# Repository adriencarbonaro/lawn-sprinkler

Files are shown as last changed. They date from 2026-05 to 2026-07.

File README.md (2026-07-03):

# Lawn sprinkler controller

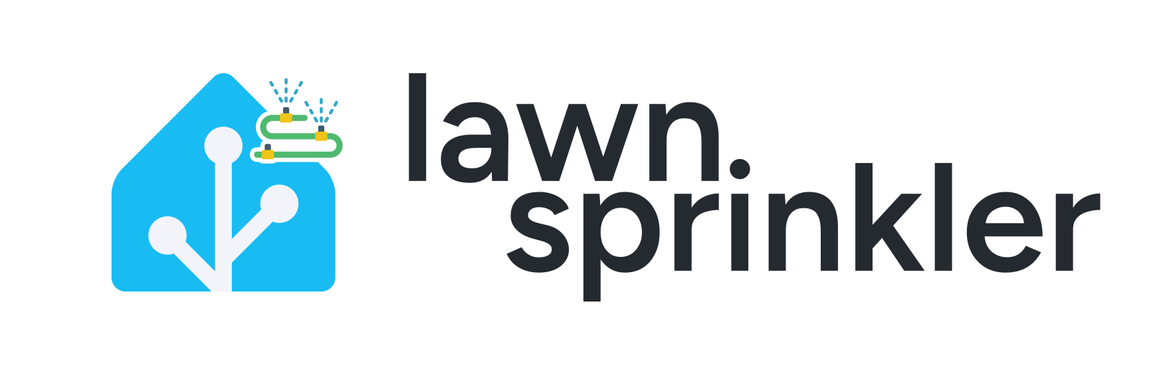
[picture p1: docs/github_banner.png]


## 1. Overview

ESP32 based firmware (ESP-IDF / FreeRTOS) for a 6-zone lawn-sprinkler controller.
Drives 6 active-high triac outputs with mutual exclusion (only one zone
ever on at a time), and use 6 ON/OFF buttons for Home Assistant.

State is exchanged over MQTT, and on (re)connect
the device publishes a single Home Assistant device-discovery payload — all
entities (mode select, duration select, six per-zone switches, version sensor)
appear grouped under one device, no manual HA configuration required.

## 2. Features

### 2.1. **MANUAL mode** :

1. On the control box:

    a) Pressing one of the 6 push buttons starts watering the zone and stops watering the other zones.

    b) Pressing it a second time stops watering the zone.

    c) If AUTO mode is active, it switches to manual mode.

    d) The system automatically returns to AUTO mode after 30 minutes without a zone being manually activated.

2. On the HA app:

    Set a duration, then select a zone to water.

### 2.2. Status LED

- **STATUS LED** : gives indication on the status of the lawn sprinkler controller
  - OFF: The device is turned off
  - Solid ON: The device is booting up
  - low flashing (100ms ON, 3000ms period): The device is connected to Wi-Fi/MQTT
  - Fast flashing (500ms ON, 1000ms period): The device was unable to connect to Wi-Fi/MQTT
- **Zone LED** : Each zone has a LED indicating whether the zone is active or not-
  - ON : the zone is currently active
  - OFF: the zone is inactive

## 3. Hardware

### 🙌 Sponsor

Huge thanks to **PCBWay** for sponsoring the PCB manufacturing for this project.
Their support, help and advices helped make this project physically real.

If you're looking for high-quality PCB fabrication or assembly services, check them out:

👉 https://www.pcbway.com

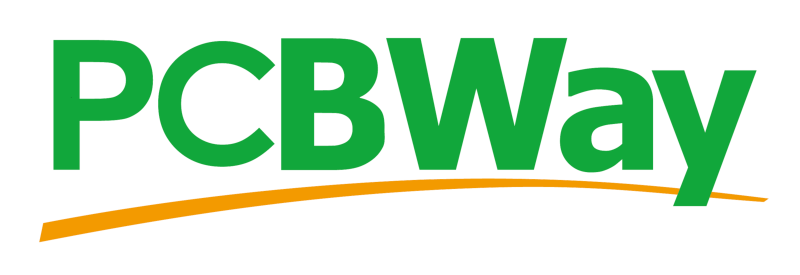
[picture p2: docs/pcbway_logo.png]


Designed around a Waveshare esp32-C6 dev kit N8.
Drives 6 triac BT136-600 in Dpak package
Uses former Rainbird ESP-RXZe controller housing and its 24Vac/0.65A transformer

## 4. Software

Developped with esp idf on freeRTOS architecture

### 4.1. Build & flash

```bash
. $IDF_PATH/export.sh
make build
make flash PORT=/dev/<port> # example: /dev/ttyACM0
make monitor
```

`make_version.py` derives `VERSION` and `BUILD_ID_SHORT` from `git describe`,
so make sure at least one tag exists (e.g. `git tag v0.1.0`).

### 4.2. Project layout

```
main/
  zone/        6 active-high outputs (MOC3041 triac drivers), mutual exclusion
  button/      6 push buttons via iot_button, one click -> controller event
  controller/  AUTO/MANUAL state machine, run/idle timers
  wifi/        Wi-Fi STA + SNTP/timezone
  mqtt/        MQTT client, topic dispatcher, Home Assistant discovery
```

### 4.3. Configuration

Set via `idf.py menuconfig` -> *Lawn Sprinkler Controller Settings*:

### 4.4. MQTT API

With `MQTT_TOPIC_PREFIX = "lawn-sprinkler/"`:

#### Subscribed (HA -> device)

| Topic | Payload | Effect |
| --- | --- | --- |
| `lawn-sprinkler/mode/set` | `AUTO` \| `MANUAL`  | Switch mode |
| `lawn-sprinkler/duration/set` | minutes (e.g. `10`) | Set MANUAL default duration |
| `lawn-sprinkler/zone/<n>/set` | `ON` \| `OFF` | Toggle zone (uses the current MANUAL duration) |

#### Published (device -> HA), retained

| Topic | Payload |
| --- | --- |
| `lawn-sprinkler/mode/state` | `AUTO` \| `MANUAL` |
| `lawn-sprinkler/duration/state` | minutes (e.g. `10`) |
| `lawn-sprinkler/zone/<n>/state` | `ON` \| `OFF` |
| `lawn-sprinkler/availability` | `online` (LWT: `offline`)  |
| `lawn-sprinkler/version` | `vX.Y.Z - <git-short-sha>` |

### 4.5. Home Assistant discovery

On every (re)connect the device publishes a single retained message using
Home Assistant's device-based discovery:

- `homeassistant/device/<DEVICE_ID>/config`

The payload describes the device once and lists every component nested under
`components`:

- `mode` - select (`AUTO` / `MANUAL`)
- `duration` - number (`0..60` minutes, `step=1`) — default applied to a manual button press
- `zone_0` ... `zone_5` - one switch per zone
- `version` - diagnostic sensor (firmware version + short build id)

Shared `device`, `origin` and `availability` blocks live at the top of the
payload, so all entities are grouped under one device in HA and follow the
same online/offline state via the `availability` topic.

### 4.6 Home Assistant card

Notes:

- This example uses `custom:button-card` which must be downloaded first. If you want a simpler option using only the UI, you can display the switches from MQTT discovery.

First, we need to create the template in Dashboard UI. This prevent a lot of duplication, as we will need it for each zone button. Go to your dashboard, then click *Edit* > *Raw Configuration Editor*. Paste the following snippet at the top. Modify the colors and style according to your needs.

```yml
button_card_templates:
  lawn_sprinkler_button_base:
    icon: mdi:sprinkler-variant
    show_name: true
    show_state: false
    layout: icon_name
    styles:
      card:
        - padding: 8px
        - height: 48px
        - border-radius: 12px
        - '--zone-color': var(--blue-color)
      name:
        - padding-left: 0px
        - color: var(--zone-color)
        - justify-self: start
        - font-size: 10pt
        - font-weight: 500
      icon:
        - width: 26px
        - height: 26px
        - color: var(--zone-color)
    state:
      - value: 'on'
        styles:
          card:
            - background-color: var(--zone-color)
          icon:
            - color: white
    tap_action:
      action: call-service
      service: switch.toggle
```

Then, create the cards.

```yml
type: vertical-stack
cards:
  - type: horizontal-stack
    cards:
      - type: tile
        entity: select.lawn_sprinkler_mode
        features_position: bottom
        vertical: false
        color: deep-orange
        name: Mode
        hide_state: false
        state_content:
          - state
          - last_changed
        grid_options:
          columns: full
        icon_tap_action:
          action: none
        tap_action:
          action: more-info
      - type: tile
        entity: select.lawn_sprinkler_duration
        features_position: bottom
        vertical: false
        name: Duration
        hide_state: false
        state_content:
          - state
        icon_tap_action:
          action: none
        tap_action:
          action: more-info
  - type: horizontal-stack
    cards:
      - type: custom:button-card
        template: lawn_sprinkler_button_base
        entity: switch.lawn_sprinkler_zone_0
        name: ZONE_1
        styles:
          card:
            - "--zone-color": var(--blue-color)
        tap_action:
          action: call-service
          service: switch.toggle
          target:
            entity_id: switch.lawn_sprinkler_zone_0
      - type: custom:button-card
        template: lawn_sprinkler_button_base
        entity: switch.lawn_sprinkler_zone_1
        name: ZONE_2
        styles:
          card:
            - "--zone-color": var(--green-color)
        tap_action:
          action: call-service
          service: switch.toggle
          target:
            entity_id: switch.lawn_sprinkler_zone_1
      - type: custom:button-card
        template: lawn_sprinkler_button_base
        entity: switch.lawn_sprinkler_zone_2
        name: ZONE_3
        styles:
          card:
            - "--zone-color": var(--purple-color)
        tap_action:
          action: call-service
          service: switch.toggle
          target:
            entity_id: switch.lawn_sprinkler_zone_2
  - type: horizontal-stack
    cards:
      - type: custom:button-card
        template: lawn_sprinkler_button_base
        entity: switch.lawn_sprinkler_zone_3
        name: ZONE_4
        styles:
          card:
            - "--zone-color": var(--red-color)
        tap_action:
          action: call-service
          service: switch.toggle
          target:
            entity_id: switch.lawn_sprinkler_zone_3
      - type: custom:button-card
        template: lawn_sprinkler_button_base
        entity: switch.lawn_sprinkler_zone_4
        name: ZONE_5
        styles:
          card:
            - "--zone-color": var(--cyan-color)
        tap_action:
          action: call-service
          service: switch.toggle
          target:
            entity_id: switch.lawn_sprinkler_zone_4
      - type: custom:button-card
        template: lawn_sprinkler_button_base
        entity: switch.lawn_sprinkler_zone_5
        name: ZONE_6
        styles:
          card:
            - "--zone-color": var(--yellow-color)
        tap_action:
          action: call-service
          service: switch.toggle
          target:
            entity_id: switch.lawn_sprinkler_zone_5
```

Notes:

- The entity names must match between the MQTT discovery and the yml snippet.

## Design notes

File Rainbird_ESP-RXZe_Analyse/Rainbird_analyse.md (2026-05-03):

# Lawn Sprinkler Controller
# RAINBIRD ESP-RXZe

## 1. Description

### 1.1 External description

**EVs wiring**
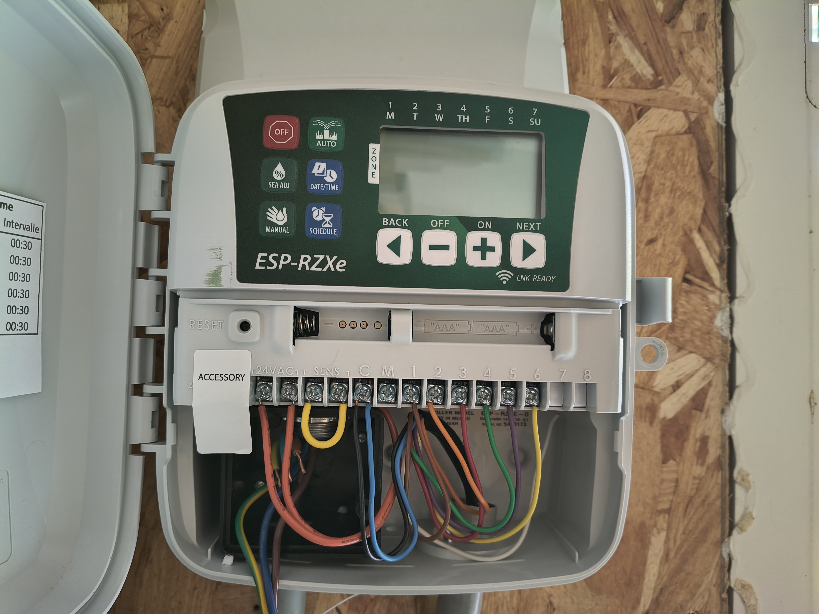
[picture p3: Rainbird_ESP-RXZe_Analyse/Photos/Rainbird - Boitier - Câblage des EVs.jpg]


**Electronic board removed**
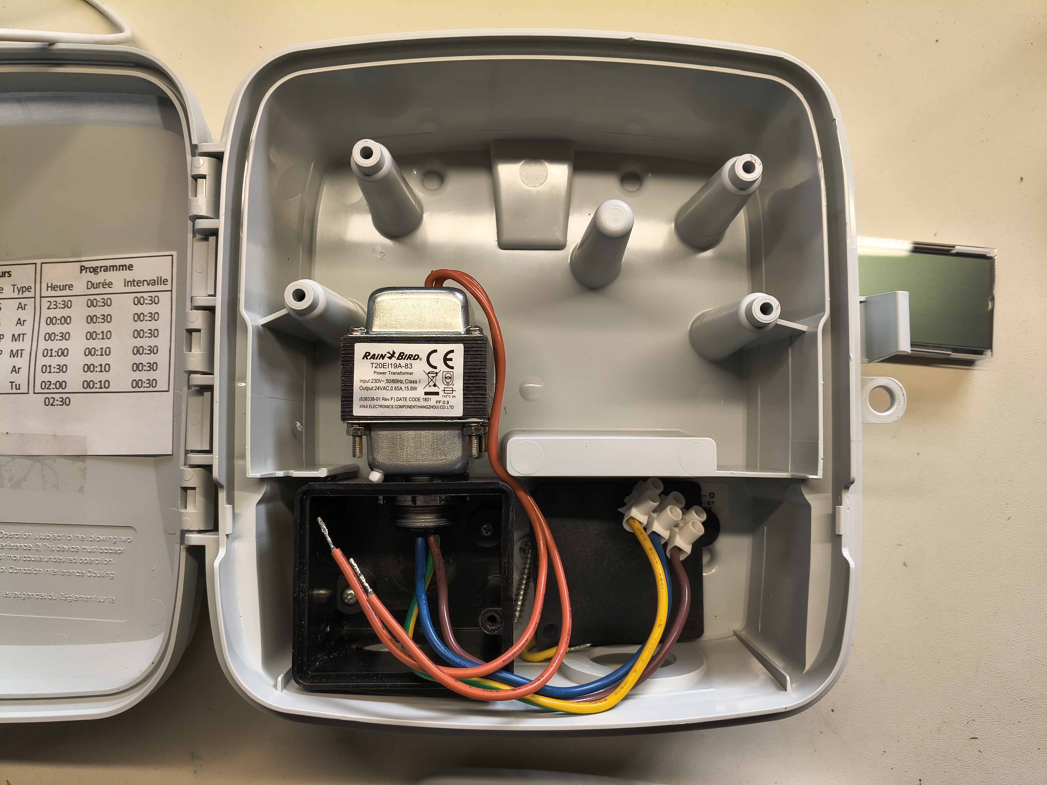
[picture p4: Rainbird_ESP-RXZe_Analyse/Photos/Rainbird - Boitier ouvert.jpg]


**User manual**
RAINBIRD - Programmateur Arrosage ESP-RZ - User manual Fr.pdf

### 1.2. Main components

**Electronic card - Rear view**
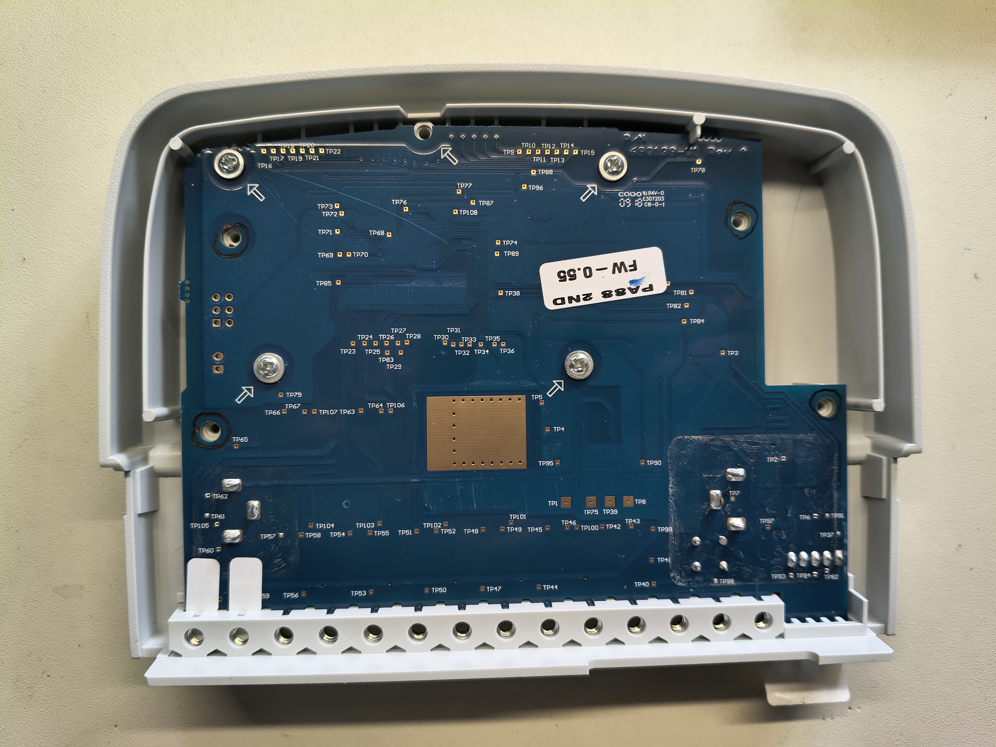
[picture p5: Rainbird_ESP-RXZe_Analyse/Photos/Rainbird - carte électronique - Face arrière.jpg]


**Electronic card - Component side**
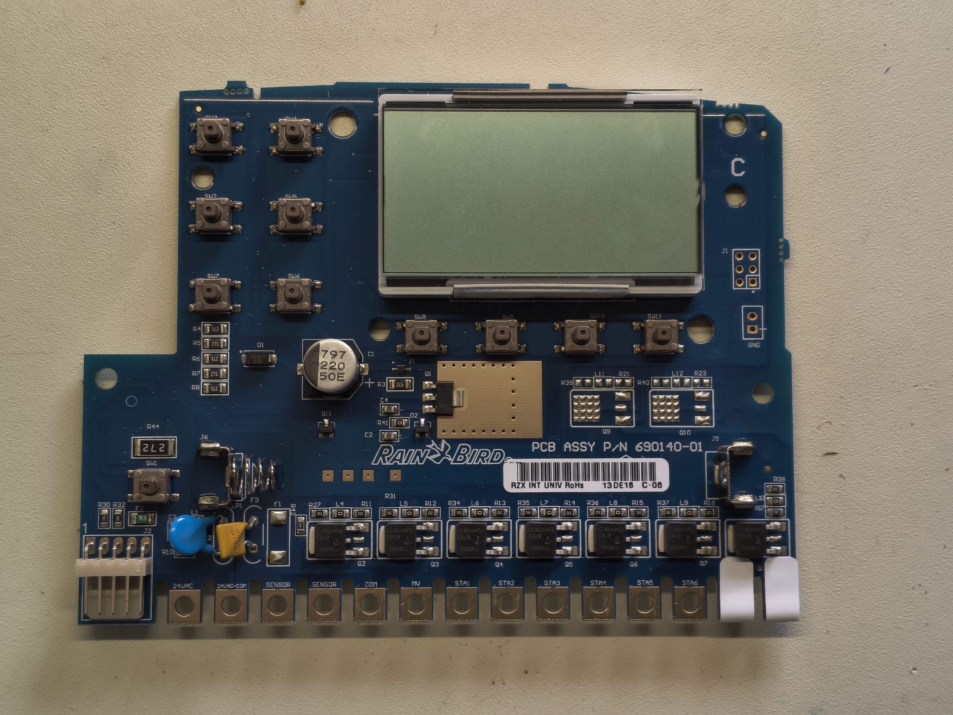
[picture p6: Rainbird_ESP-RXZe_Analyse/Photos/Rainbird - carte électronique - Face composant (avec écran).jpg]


- **Micro controller**
MC9S08LL64CLH : 8-bit microcontroller from the NXP S08 series  
8-Bit S08 Central Processor
Speed of 40MHz enabling quick processing
64KB Flash Memory for program storage
4KB RAM for data handling
Multiple connectivity options including I2C, SCI, SPI interfaces
Integrated peripherals such as LCD Driver, LVD, POR, PWM, WDT
37 programmable I/O pins for versatile use
Internal 12-bit analog-to-digital converters (8 channels)
Operational over a wide voltage range (1.8V to 3.6V)
Built-in oscillator for system clock generation
Supply Device Package: 64-LQFP (10x10)  

- **24 V Transformer** 
RainBird T20EI 19A-83
Input 230V : Output 24V AC, 0,65A, 15,6W  
Output no charge : 19,62 V measured  
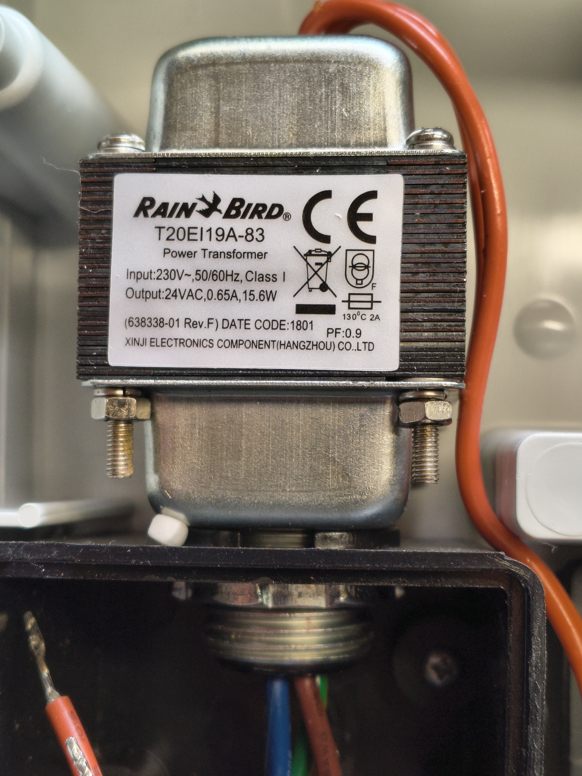
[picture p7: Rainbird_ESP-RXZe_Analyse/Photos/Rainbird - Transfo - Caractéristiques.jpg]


Version finale

### Schematics

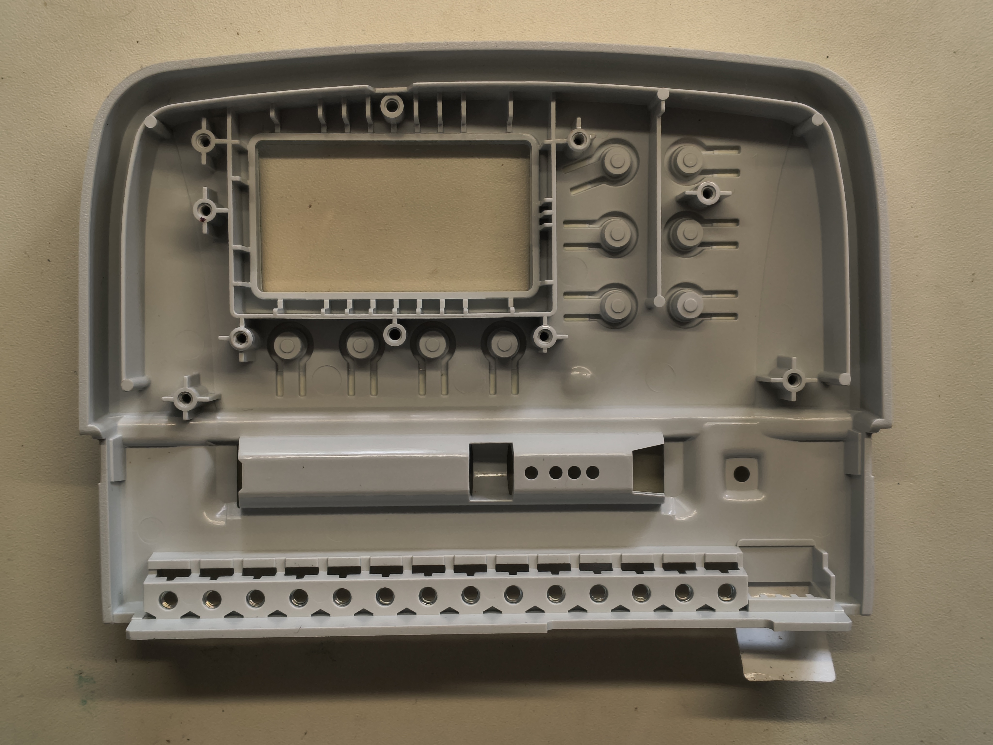
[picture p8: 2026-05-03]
Rainbird_ESP-RXZe_Analyse/Photos/Rainbird - capot supérieur - Face interne.jpg

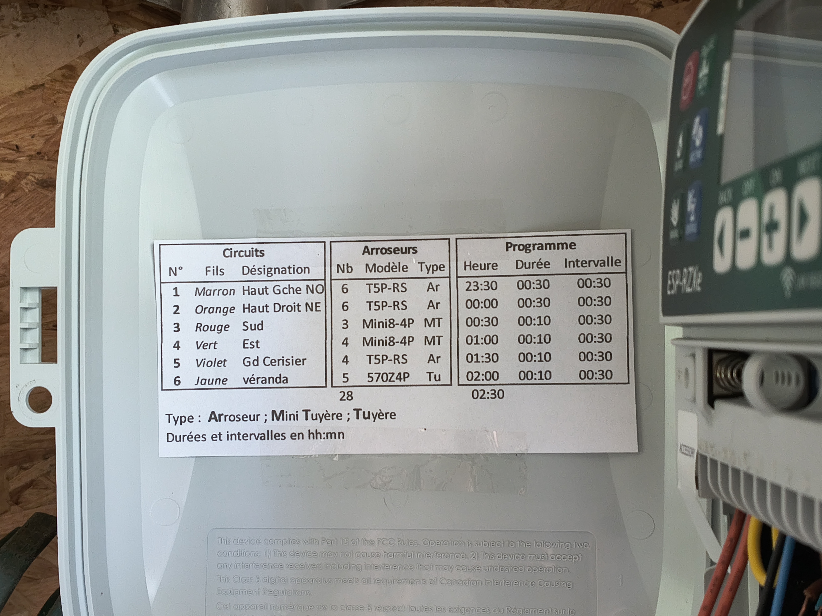
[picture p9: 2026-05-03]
Rainbird_ESP-RXZe_Analyse/Photos/Horaires arrosage.jpg

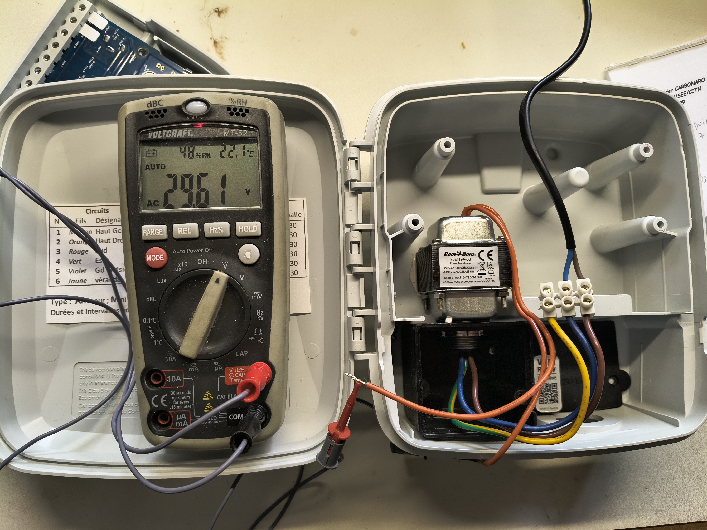
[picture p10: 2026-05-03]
Rainbird_ESP-RXZe_Analyse/Photos/Rainbird - Transfo - Tension de sortie.jpg

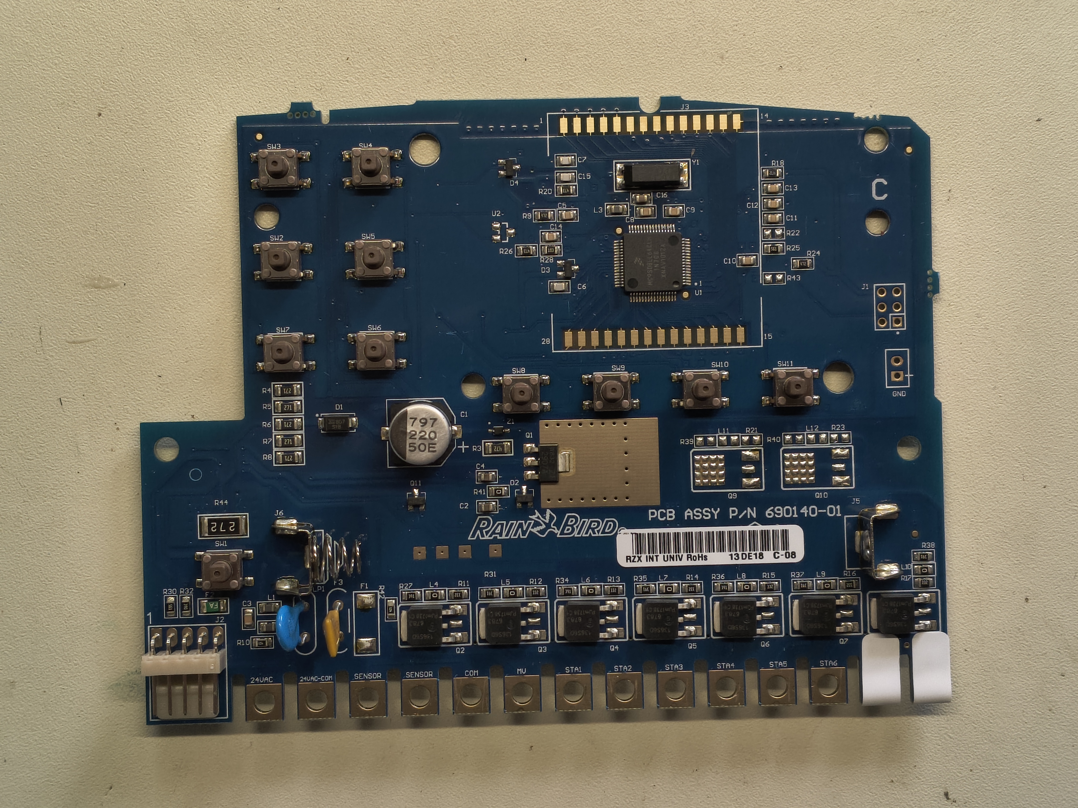
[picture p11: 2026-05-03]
Rainbird_ESP-RXZe_Analyse/Photos/Rainbird - carte électronique - Face composant (sans écran).jpg

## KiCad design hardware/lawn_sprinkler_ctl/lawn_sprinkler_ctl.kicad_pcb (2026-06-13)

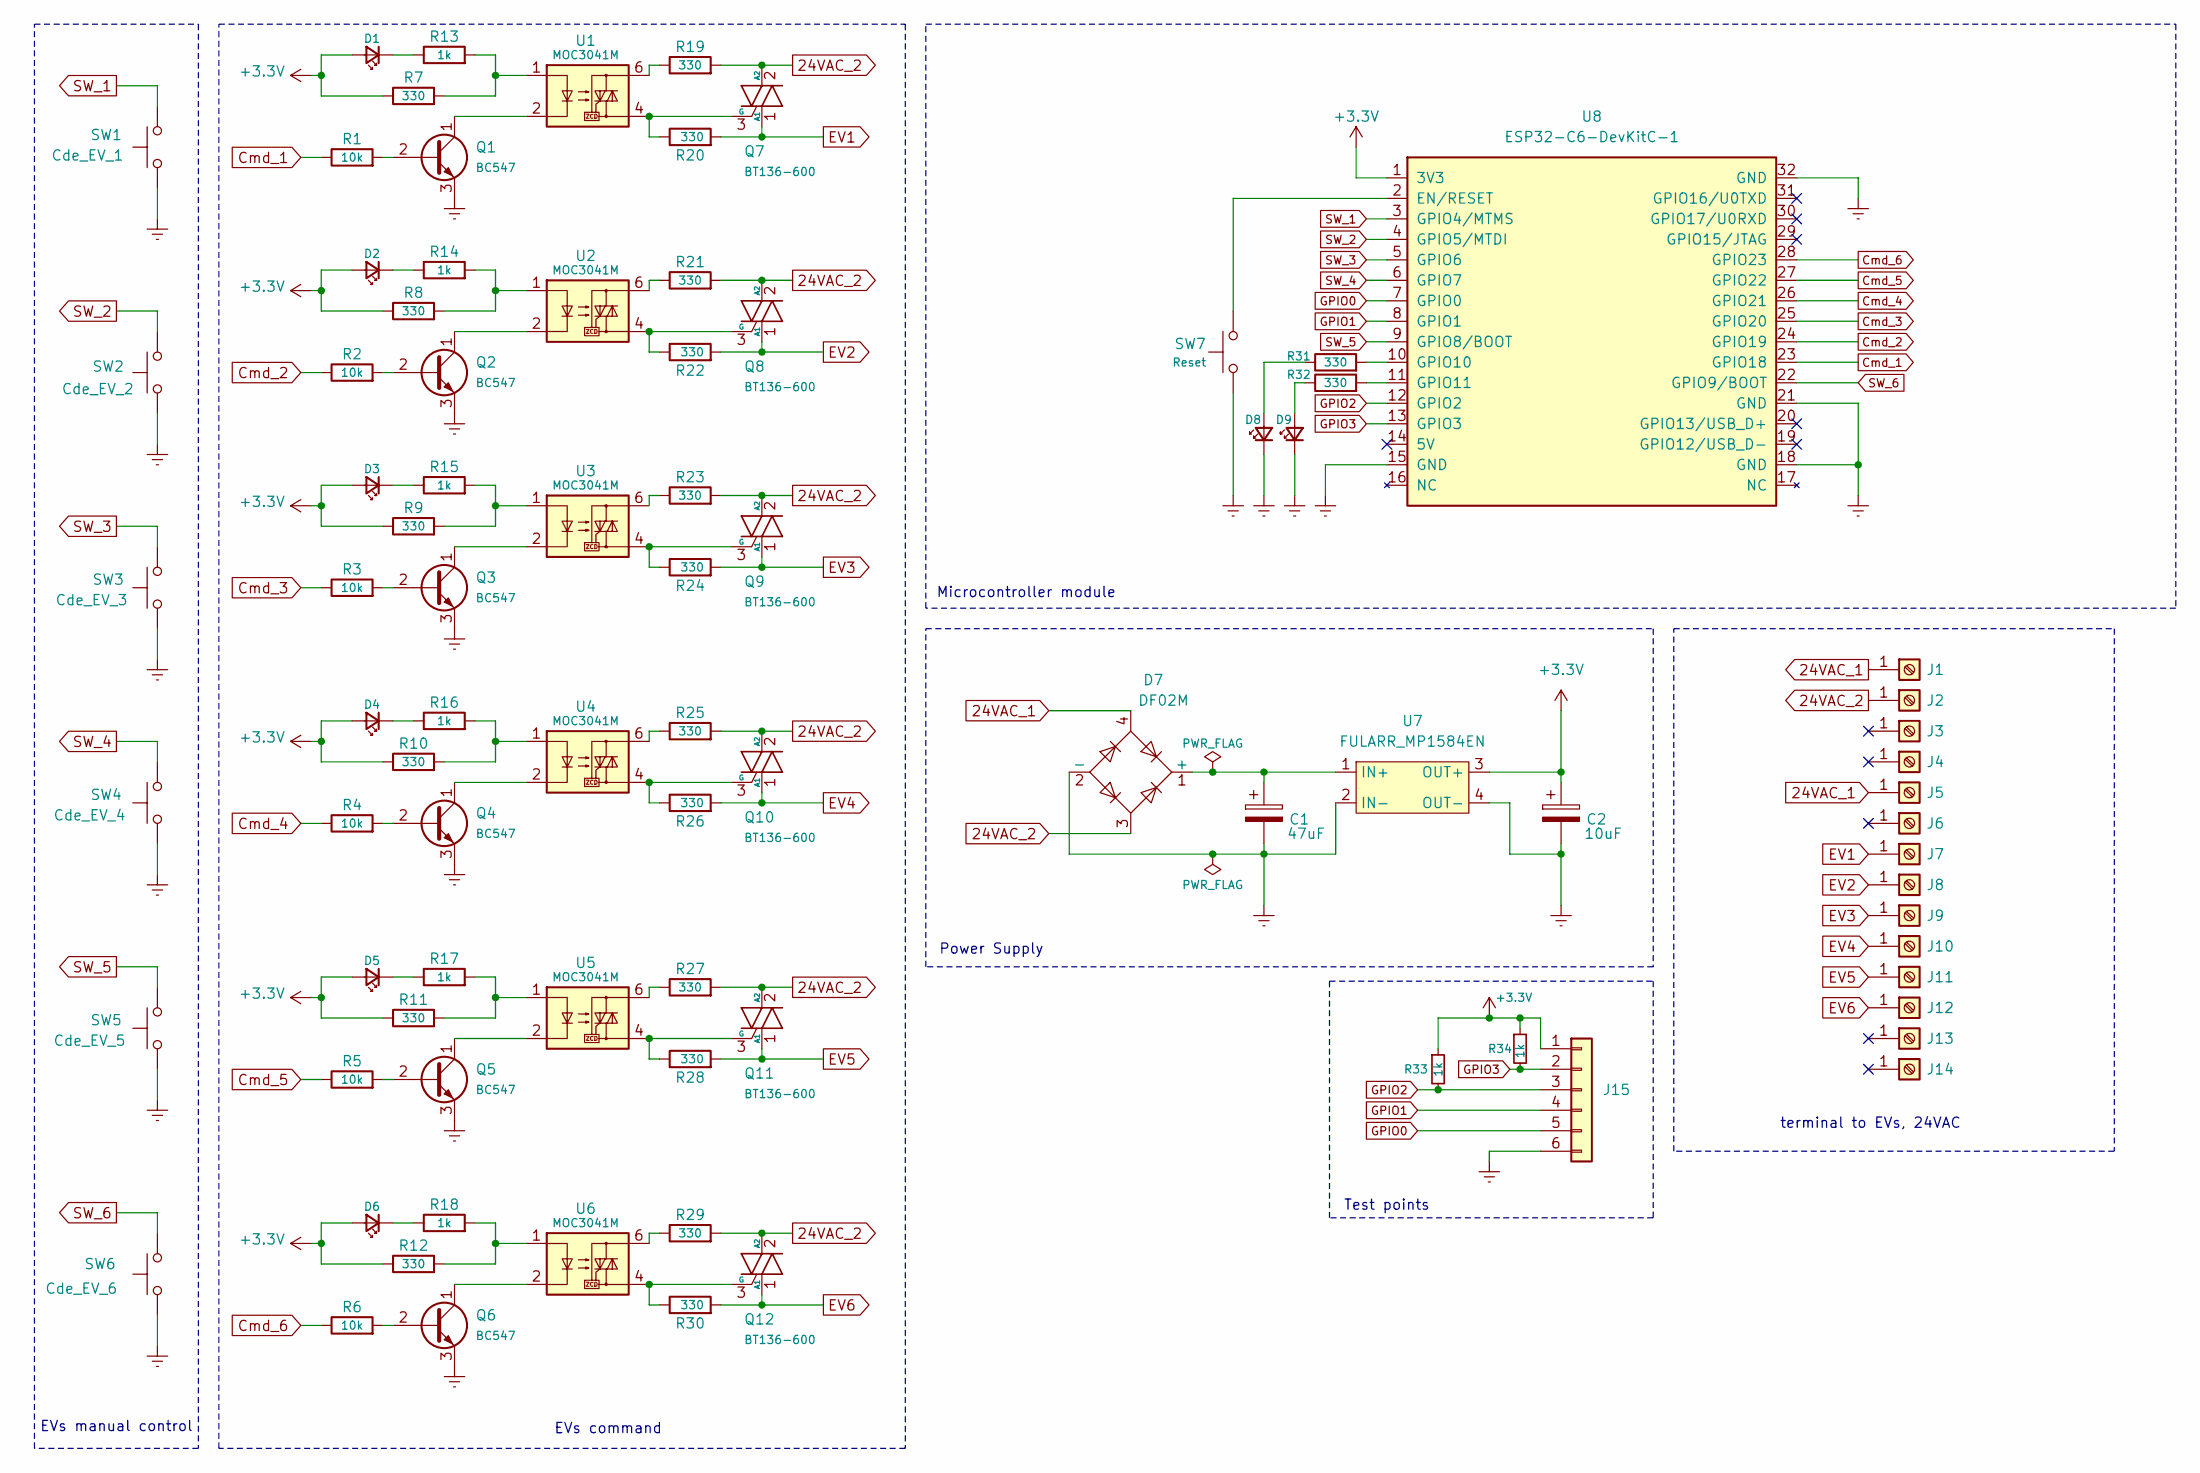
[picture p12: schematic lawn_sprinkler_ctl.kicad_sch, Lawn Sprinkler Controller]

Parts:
C1: 47uF; CP_Radial_D8.0mm_P3.50mm
C2: 10uF; C_Radial_D5.0mm_H11.0mm_P2.00mm
D1, D2, D3, D4, D5, D6, D8, D9: LED; LED_D5.0mm
D7: DF02M; Diode_Bridge_DIP-4_W7.62mm_P5.08mm
J1, J2, J3, J4, J5, J6, J7, J8, J9, J10, J11, J12, J13, J14: Screw_Terminal_01x01; square_pad
J15: Conn_01x04; PinHeader_1x06_P2.54mm_Vertical
Q1, Q2, Q3, Q4, Q5, Q6: BC547; TO-92_Inline
Q7, Q8, Q9, Q10, Q11, Q12: BT136-600; TO-252-3_TabPin2
R1, R2, R3, R4, R5, R6: 10k; R_0805_2012Metric_Pad1.20x1.40mm_HandSolder
R7, R8, R9, R10, R11, R12, R19, R20, R21, R22, R23, R24, R25, R26, R27, R28, R29, R30, R31, R32: 330; R_0805_2012Metric_Pad1.20x1.40mm_HandSolder
R13, R14, R15, R16, R17, R18, R33, R34: 1k; R_0805_2012Metric_Pad1.20x1.40mm_HandSolder
SW1: Cde_EV_1; SW_PUSH-12mm_Wuerth-430476085716
SW2: Cde_EV_2; SW_PUSH-12mm_Wuerth-430476085716
SW3: Cde_EV_3; SW_PUSH-12mm_Wuerth-430476085716
SW4: Cde_EV_4; SW_PUSH-12mm_Wuerth-430476085716
SW5: Cde_EV_5; SW_PUSH-12mm_Wuerth-430476085716
SW6: Cde_EV_6; SW_PUSH-12mm_Wuerth-430476085716
SW7: Reset; SW_PUSH-12mm_Wuerth-430476085716
U1, U2, U3, U4, U5, U6: MOC3041M; DIP-6_W7.62mm
U7: FULARR_MP1584EN
U8: ESP32-C6-DevKitC-1; ESP32-C6_DevKit_N8

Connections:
24VAC_1: D7.4, J1.1, J5.1
24VAC_2: D7.3, J2.1, Q7.2 (A2), Q8.2 (A2), Q9.2 (A2), Q10.2 (A2), Q11.2 (A2), Q12.2 (A2), R19.2, R21.2, R23.2, R25.2, R27.2, R29.2
+3.3V: C2.1, D1.2 (A), D2.2 (A), D3.2 (A), D4.2 (A), D5.2 (A), D6.2 (A), J15.1, R7.1, R8.1, R9.1, R10.1, R11.1, R12.1, R33.1, R34.1, U7.3 (OUT+), U8.1 (3V3)
Cmd_1: R1.1, U8.23 (GPIO18)
Cmd_2: R2.1, U8.24 (GPIO19)
Cmd_3: R3.1, U8.25 (GPIO20)
Cmd_4: R4.1, U8.26 (GPIO21)
Cmd_5: R5.1, U8.27 (GPIO22)
Cmd_6: R6.1, U8.28 (GPIO23)
EV1: J7.1, Q7.1 (A1), R20.2
EV2: J8.1, Q8.1 (A1), R22.2
EV3: J9.1, Q9.1 (A1), R24.2
EV4: J10.1, Q10.1 (A1), R26.2
EV5: J11.1, Q11.1 (A1), R28.2
EV6: J12.1, Q12.1 (A1), R30.2
GND: C1.2, C2.2, D7.2 (-), D8.1 (K), D9.1 (K), J15.6, Q1.3 (E), Q2.3 (E), Q3.3 (E), Q4.3 (E), Q5.3 (E), Q6.3 (E), SW1.1, SW2.1, SW3.1, SW4.1, SW5.1, SW6.1, SW7.1, U7.2 (IN-), U7.4 (OUT-), U8.15 (GND), U8.18 (GND), U8.21 (GND), U8.32 (GND)
GPIO0: J15.5, U8.7 (GPIO0)
GPIO1: J15.4, U8.8 (GPIO1)
GPIO2: J15.3, R33.2, U8.12 (GPIO2)
GPIO3: J15.2, R34.2, U8.13 (GPIO3)
unnamed: D1.1 (K), R13.1
unnamed: D2.1 (K), R14.1
unnamed: D3.1 (K), R15.1
unnamed: D4.1 (K), R16.1
unnamed: D5.1 (K), R17.1
unnamed: D6.1 (K), R18.1
unnamed: C1.1, D7.1 (+), U7.1 (IN+)
unnamed: D8.2 (A), R31.1
unnamed: D9.2 (A), R32.1
unnamed: Q1.2 (B), R1.2
unnamed: Q1.1 (C), U1.2
unnamed: Q2.2 (B), R2.2
unnamed: Q2.1 (C), U2.2
unnamed: Q3.2 (B), R3.2
unnamed: Q3.1 (C), U3.2
unnamed: Q4.2 (B), R4.2
unnamed: Q4.1 (C), U4.2
unnamed: Q5.2 (B), R5.2
unnamed: Q5.1 (C), U5.2
unnamed: Q6.2 (B), R6.2
unnamed: Q6.1 (C), U6.2
unnamed: Q7.3 (G), R20.1, U1.4
unnamed: Q8.3 (G), R22.1, U2.4
unnamed: Q9.3 (G), R24.1, U3.4
unnamed: Q10.3 (G), R26.1, U4.4
unnamed: Q11.3 (G), R28.1, U5.4
unnamed: Q12.3 (G), R30.1, U6.4
unnamed: R10.2, R16.2, U4.1
unnamed: R11.2, R17.2, U5.1
unnamed: R12.2, R18.2, U6.1
unnamed: R7.2, R13.2, U1.1
unnamed: R8.2, R14.2, U2.1
unnamed: R9.2, R15.2, U3.1
unnamed: R19.1, U1.6
unnamed: R21.1, U2.6
unnamed: R23.1, U3.6
unnamed: R25.1, U4.6
unnamed: R27.1, U5.6
unnamed: R29.1, U6.6
unnamed: SW7.2, U8.2 (EN/RESET)
unnamed: R31.2, U8.10 (GPIO10)
unnamed: R32.2, U8.11 (GPIO11)
SW_1: SW1.2, U8.3 (GPIO4/MTMS)
SW_2: SW2.2, U8.4 (GPIO5/MTDI)
SW_3: SW3.2, U8.5 (GPIO6)
SW_4: SW4.2, U8.6 (GPIO7)
SW_5: SW5.2, U8.9 (GPIO8/BOOT)
SW_6: SW6.2, U8.22 (GPIO9/BOOT)

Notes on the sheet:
EVs manual control
Test points
terminal to EVs, 24VAC
Microcontroller module
EVs command
Power Supply

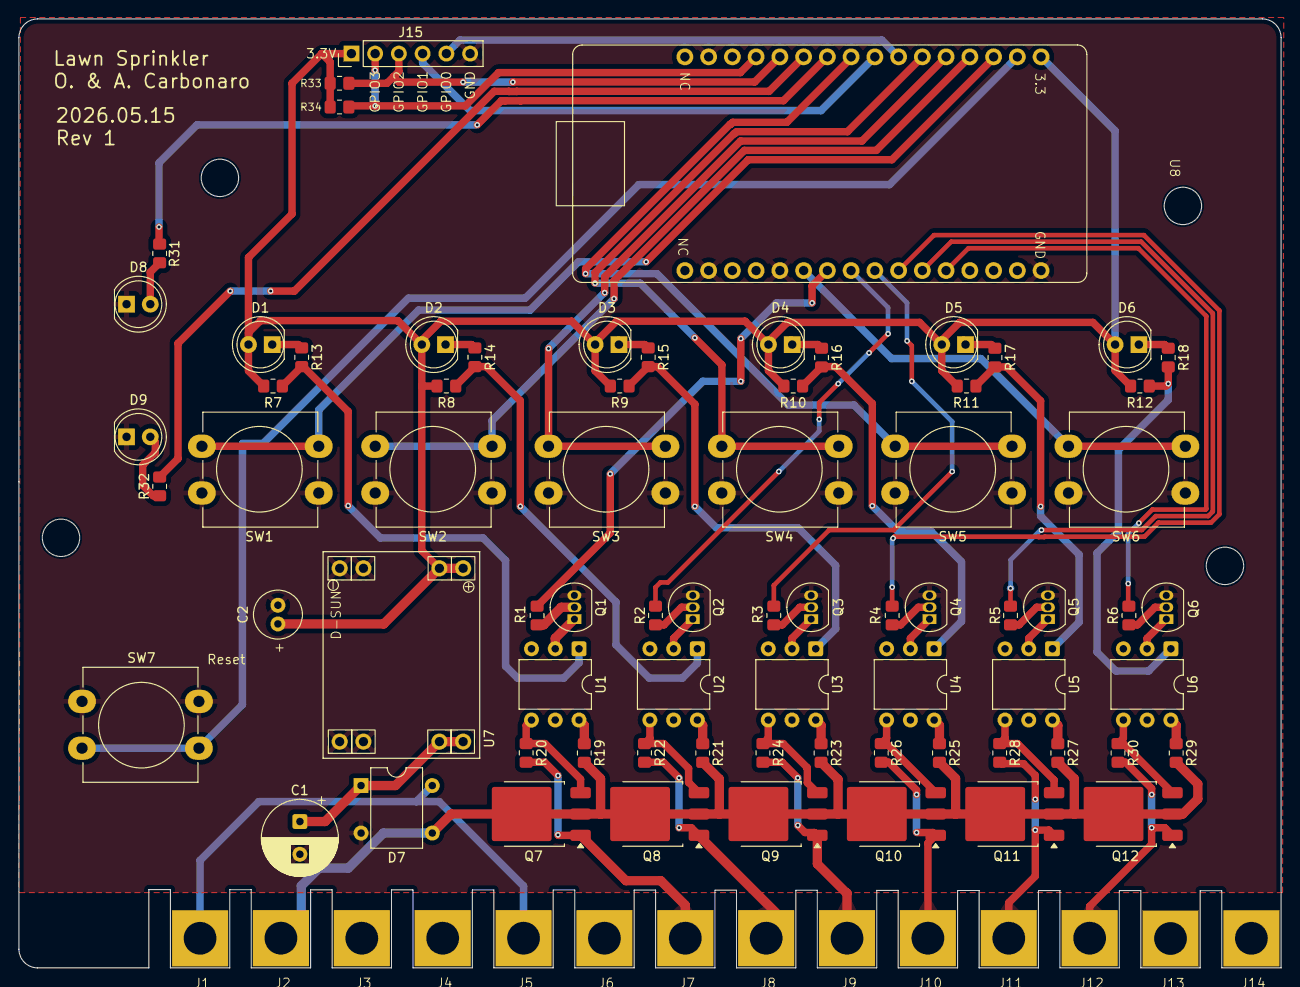
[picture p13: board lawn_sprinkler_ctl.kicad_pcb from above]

Board: 2 copper layers, 135.0 x 101.5 mm, 87 parts (0 on the bottom side), 68 nets.

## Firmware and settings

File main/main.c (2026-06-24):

#include "button.h"
#include "config.h"
#include "controller.h"
#include "ha_entities.h"
#include "led.h"
#include "mqtt.h"
#include "version.h"
#include "wifi.h"
#include "zone.h"

static const ha_identity_t identity = {
    .device_id = CONFIG_DEVICE_ID,
    .device_name = CONFIG_DEVICE_NAME,
    .manufacturer = CONFIG_MANUFACTURER,
    .model = CONFIG_ESP32_MODEL,
    .version_str = DESCRIBE,
};

static void on_wifi_connect(void) { mqtt_start(); }

static void on_wifi_disconnect(void)
{
    /* Covers both retries and a sustained inability to connect. */
    led_set_status(STATUS_LED_CONNECTING);
}

static void on_mqtt_connect(void)
{
    led_set_status(STATUS_LED_CONNECTED);
    controller_publish_state();
}

void app_main(void)
{
    /* Status LED solid while we bring the device up. */
    led_init();

    /* Init Home Assistant layer */
    uint16_t nb_entities = 0;
    const ha_entity_t* entities = get_entities(&nb_entities);
    ha_init(&identity, entities, nb_entities);

    mqtt_set_on_connect(on_mqtt_connect);

    /* User init */
    zone_init();
    controller_init();
    button_init();

    led_set_status(STATUS_LED_CONNECTING);
    wifi_init(on_wifi_connect, on_wifi_disconnect);
}

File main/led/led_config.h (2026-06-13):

#ifndef LED_CONFIG_H_
#define LED_CONFIG_H_

#include "sdkconfig.h"

#define LED_ACTIVE_LEVEL 1

#define GPIO_LED_STATUS CONFIG_GPIO_LED_STATUS
#define GPIO_LED_AUTO CONFIG_GPIO_LED_AUTO

/* Status LED blink timings (milliseconds). */
#define STATUS_LED_CONNECTED_ON_MS 100
#define STATUS_LED_CONNECTED_PERIOD_MS 3000

#define STATUS_LED_CONNECTING_ON_MS 100
#define STATUS_LED_CONNECTING_OFF_MS 100

#endif /* LED_CONFIG_H_ */

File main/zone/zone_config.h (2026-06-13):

#ifndef ZONE_CONFIG_H_
#define ZONE_CONFIG_H_

#include "sdkconfig.h"

#define ZONE_ACTIVE_LEVEL 1
#define ZONE_COUNT 6

/* After this much idle time in MANUAL with no zone active, return to AUTO */
#define AUTO_MODE_RESET_TIME_MIN CONFIG_AUTO_MODE_RESET_TIME_MIN

/* Duration applied to a manual button press, in minutes. 0 = no auto-stop. */
#define DEFAULT_DURATION_MIN CONFIG_DEFAULT_DURATION_MIN

#define GPIO_ZONE_1 CONFIG_GPIO_ZONE_1
#define GPIO_ZONE_2 CONFIG_GPIO_ZONE_2
#define GPIO_ZONE_3 CONFIG_GPIO_ZONE_3
#define GPIO_ZONE_4 CONFIG_GPIO_ZONE_4
#define GPIO_ZONE_5 CONFIG_GPIO_ZONE_5
#define GPIO_ZONE_6 CONFIG_GPIO_ZONE_6

#endif /* ZONE_CONFIG_H_ */

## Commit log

2026-05-05 electronic schematic added
    [lawn_sprinkler_ctl.kicad_pcb, lawn_sprinkler_ctl.kicad_sch]
2026-05-09 kicad schematic V0.2
    [lawn_sprinkler_ctl.kicad_sch]
2026-06-13 feat: update hardware
    [lawn_sprinkler_ctl.kicad_pcb, lawn_sprinkler_ctl.kicad_sch]
2026-06-13 feat(buttons): handle GPIO with kconfig
2026-06-13 feat: use device discovery instead of component
2026-06-13 chore: remove leds gpio
2026-06-13 refactor: replace manual-idle polling with FreeRTOS timer
2026-06-13 feat: use freertos timer for run
2026-06-13 feat: use auto mode reset timer from config
    [zone_config.h]
2026-06-13 fix: do not enforce duration, leave it to client
    [zone_config.h]
2026-06-13 fix: only use min for durations outside the internal driver + removes /run endpoint who used seconds
    [zone_config.h]
2026-06-13 feat: add status led + auto mode led
2026-06-24 fix: use 921600 baud for esp32c6
2026-06-24 feat: update schematics resistors
    [lawn_sprinkler_ctl.kicad_sch]
2026-07-03 feat: update README.md and add PCBWay logo
